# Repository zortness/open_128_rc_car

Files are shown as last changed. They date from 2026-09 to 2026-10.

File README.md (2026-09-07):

# 1:28 Scale 3D Printable RC Car #
This is a collection of 3D files built in [FreeCAD](https://www.freecad.org/). 
It began as a project with a goal of making the least expensive viable RC car that
would still be suitable for competitions for STEM programs in schools. 

See the [History](doc/history.md) page for more info.

## Current State ##
As of Summer 2026, the Mid-Tier cars we've built and assembled are competitive with
box-stock cars of the main manufacturers. 

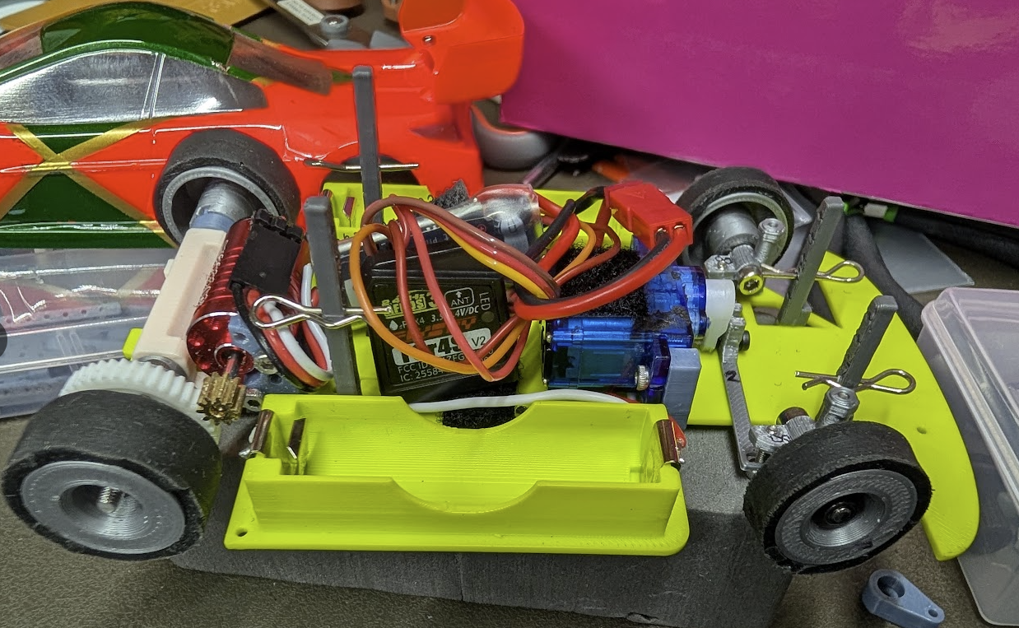
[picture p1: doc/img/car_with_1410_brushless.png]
brushless

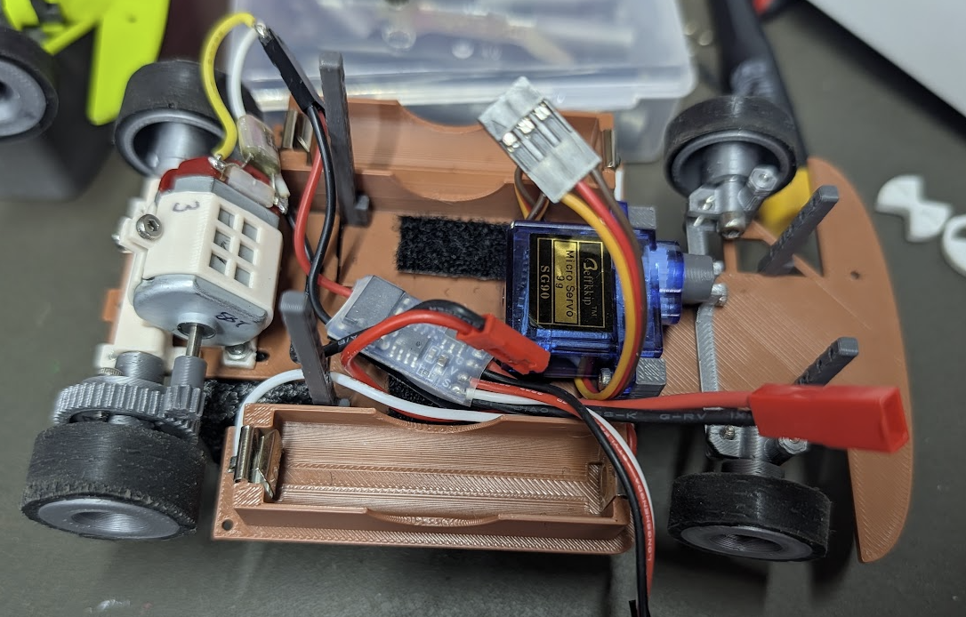
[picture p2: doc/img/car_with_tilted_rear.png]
brushed_tilted

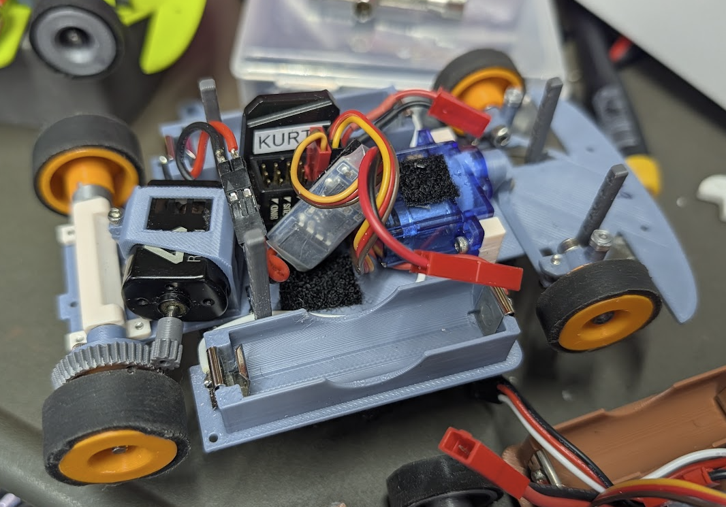
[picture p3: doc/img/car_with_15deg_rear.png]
brushed_15deg

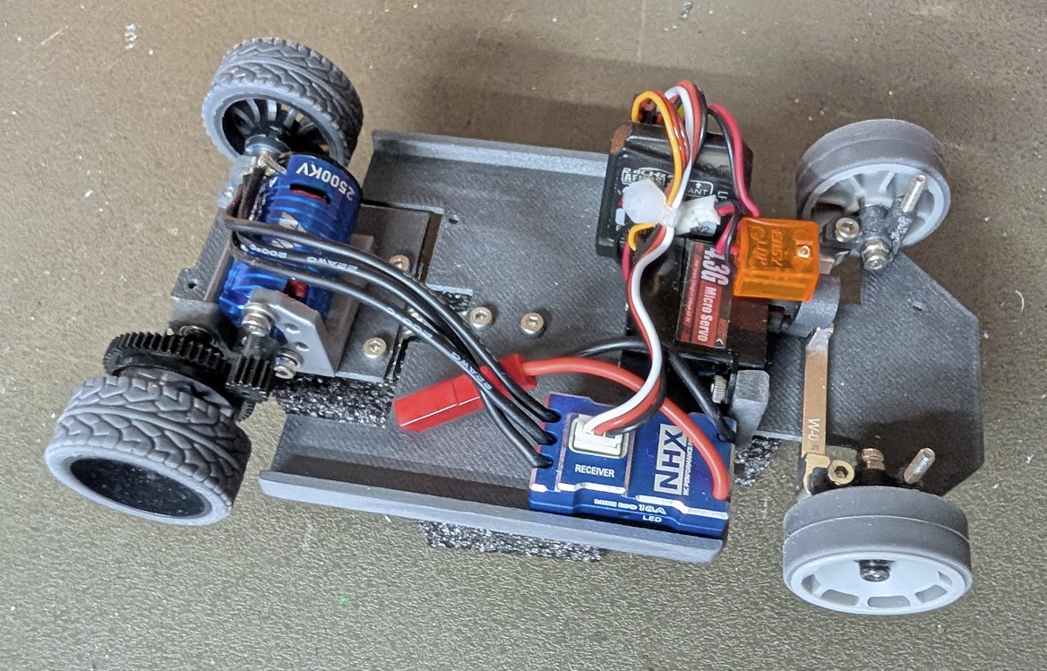
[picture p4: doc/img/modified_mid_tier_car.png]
modified


## Downloading ##
See the releases tab for the latest releases. These packages contain the most common
files and variants that should be more than enough to get you started with a functional
car.

## Materials Needed ##
You will need several [materials](doc/materials.md) and tools. This documentation
will try to walk through the recommended options to get started with the basics.

## Printing and Assembly ##
See [Getting Started](doc/gettingstarted.md).
See [Printing](doc/printing.md) and [Assembly](doc/assembly.md).

## Building from Source ##
You will need [FreeCAD 1.1](https://www.freecad.org/) or higher.
- With Gear Workbench installed (required)
- With Fasteners Workbench installed (required)
- With History Workbench installed (recommended)

You will need [Python 3.14](https://www.python.org/downloads/) or higher to run some of
the tools, like the automated exporter. See [Exporiting](doc/export.md).

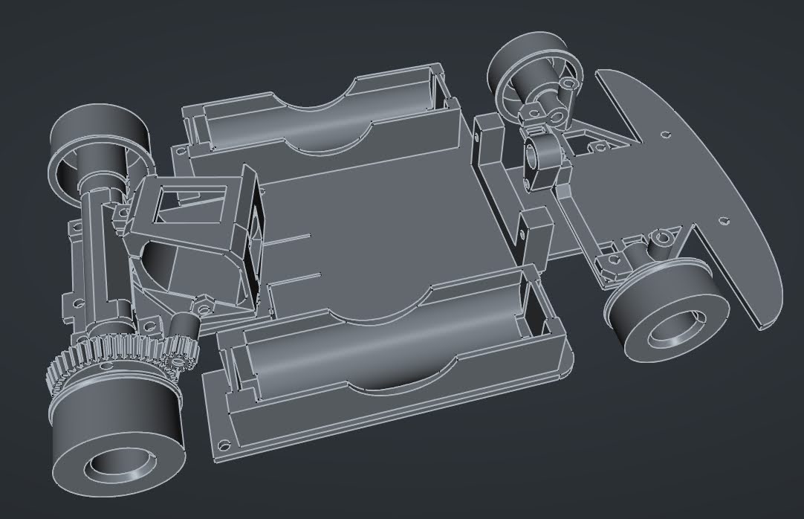
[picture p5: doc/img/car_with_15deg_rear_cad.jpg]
brushed_15deg_cad


## Advanced Topics ##
For the truly adventurous, you can make your own [tires](doc/tires/diytires.md).

## Contributing ##
See [Contributing](doc/contributing.md) for more info.

## Index ##
- [Getting Started](doc/gettingstarted.md)
- [Printing](doc/printing.md)
- [Materials](doc/materials.md)
- [Assembly](doc/assembly.md)
- [Electronics](doc/electronics.md)
- [Batteries](doc/batteries.md)
- [Trasmitters and Receivers](doc/receivers.md)
- [Tires](doc/tires/tires.md)
- [DIY Tires](doc/tires/diytires.md)
- [Exporting](doc/export.md)
- [History](doc/history.md)
- [Contributing](doc/contributing.md)
- [Licenses](LICENSE.md)

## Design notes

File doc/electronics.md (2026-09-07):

# Electronics #
There are an innumerable number of options for electronics for this project.
This section will be presented in tiers depending on budget and goals.

## Prelude ##
We recommend starting with the budget options, unless you have experience
with 1:28 scale cars and understand what the tradeoffs are. But as an example,
once you start upgrading your powertrain, you will start finding the weak points
with each connected piece of the chassis, and will need to start upgrading more
parts to keep the car running. For instance, once you go beyond a budget motor,
you can no longer 3D print your pinion gears and expect to finish a race event,
and will need to buy brass gears and corresponding equipment to manage them. 

An unmodified budget car is typically not fast by 1:28 standards, but is plenty
to get a beginner started on their journey, and plenty of fun in their own right,
especially on small or constrained tracks.

If you want to be competitive with commercially available starter-cars from the main
brands, you will need to aim for a Mid-tier build.

If you want to be competitive with commercially available high-end cars, you will
need to experiment and spend accordingly. Please share your experiments and findings
as this hasn't been achieved by our team yet.

### Transmitter and Receivers ###
See [Transmitter and Recievers](receivers.md).

### Batteries ###
See [Batteries](batteries.md).

### Motor KV ###
The KV gives some indication of the expected RPM at a given input Voltage. 
We typically don't want a high KV if the car is running at 6V or higher. The
range for these cars is typically 2500kV to 4000kV. You can use higher, but 
the car may have trouble driving slowly. If you run the car at 4V, you can use a
higher KV.

Brushed motors typically don't advertise the KV, so you might need to conversion
between Turns (how many windings of copper wire are around the rotors) to KV. 

### Electronic Speed Controller (ESC) ###
You will need to check the input voltage and type of ESC and make sure it's
compatible with your Battery choice and motor choice. Most ESCs will advertise
their upper and lower voltage limits, as well as their Current limits.

For these cars under normal conditions, we are very unlikely to see more than
a few Amps of current. If you are building a very high powered car, most of
the expensive ESCs are capable of 18-20 Amps without issue.

### Tools and Equipment ###
You will likely need a soldering iron, as many of these budget options will have
connectors that are not necessarily compatible with one another. The 
[PINECIL](https://pine64.com/product/pinecil-smart-mini-portable-soldering-iron/)
is a very popular budget soldering iron that works very well if you have a 
good USB-C charger to power it. ($26)

It is often preferrable to solder the motor to the ESC, but you will need to
have a connector setup between the battery(ies) and the ESC.

For the Servo, Receiver, and ESC to connect together, we typically use the
3-pin 0.1" (2.54mm) connectors, somtimes known as JST-XH connectors. 
If you do need to make one of these connectors, they require a crimping tool. 
You can find [these on amazon](https://www.amazon.com/2020-Piece-Connector-Ratcheting-Crimping-Terminals/dp/B0G2L3LGWD/) 
with a crimp tool and a bunch of connectors that you won't need, but it can get
you started. If you want higher quality components, I recommend using parts
from [Hansen Hobbies](https://www.hansenhobbies.com/products/connectors/servoconnectors/).

## Budget Options ##
In the budget range, you are looking for a Brushed 130 size motor. There are
hundreds of these out there to try, and they will run from about $1 to $8 a 
piece for the inexpensive variants. If you get lucky, you might be able to find 
one with carbon brushes instead of copper. Copper also works fine, but carbon 
brushes should last longer.

Copper Brushes:
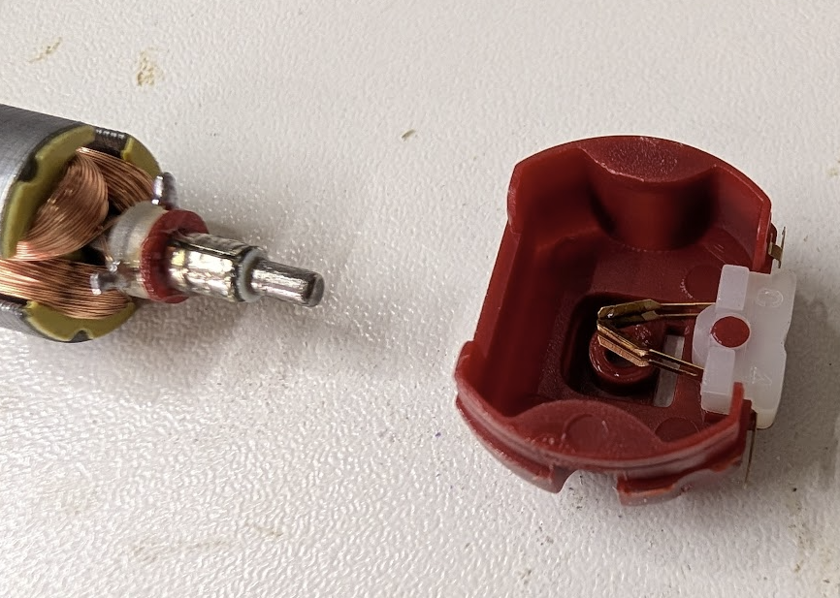
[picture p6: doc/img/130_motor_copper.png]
copper_motor


Carbon / Graphite Brushes:
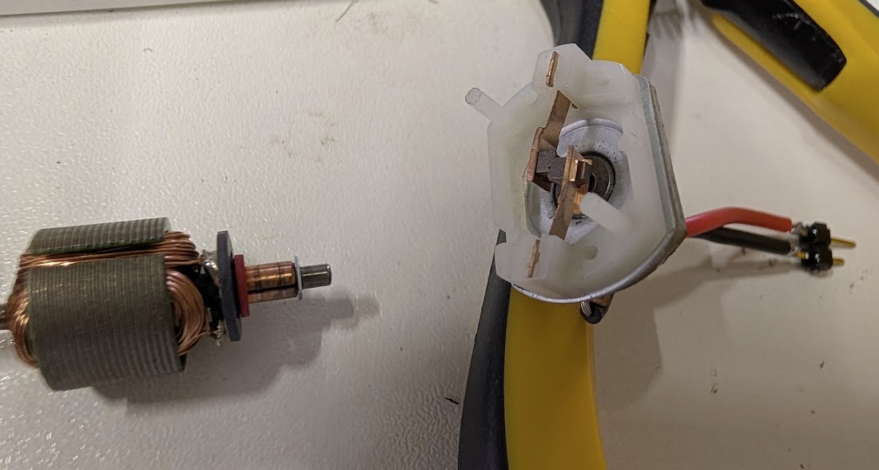
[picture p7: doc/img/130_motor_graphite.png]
carbon_motor


With these budget motors, sometimes it's possible to modify them by taking them
apart and reducing the number of windings to increase the KV. This will speed up
the motor, but likely reduce the lifespan.

budget_car

We have tested these [10-packs of inexpensive 130 motors](https://www.amazon.com/dp/B078MR3H45) 
for many hours and modified several of them. ($14 for 10)

Beware that most of the Tamiya motors are very fast, but also burn through 
brushes very quickly, as they are designed to run around 3V. 

These [6-packs of ESCs](https://www.amazon.com/dp/B0GH65NNN8) are the cheapest budget option
that we have had success with. However, we have certainly burned out a few of these.
The build quality and QA are not great. ($17 for 6)

For the servo, you do not need to spend a lot of money here, especially on a lower
powered car. What you gain in servo upgrades are turning speed and size/weight.
The inexpensive [10-packs of servos](https://www.amazon.com/dp/B08KY49SFX) in the
ubiquitous cheap-servo-blue cases are a great budget option. ($19 for 10)

## Mid-Tier Options ##
There are numerous Brushed Motor and ESC combinations advertised on Ebay and AliExpress.

### Brushed ###
Racing Brushed Motor and ESC.
- [TG Racing 130 Motors on AliExpress](https://www.aliexpress.us/item/3256808970209600.html) ($10 for 1)

tg_motor

### Brushless ###
Budget Brushless Motor and ESC.
- [NHX 2500KV Brushless Motor and ESC Combo on Ebay](https://www.ebay.com/itm/133949755095) ($60)
- [YSIDIO 1410 Brushless Motor and ESC on AliExpress](https://www.aliexpress.us/item/3256805346661858.html) ($37)

ysidio_motor
nhx_motor

### Servos ###
You are looking for inexpensive metal gear servos for speed and durability:
- [MG90s Metal Gear Servo on Amazon](https://www.amazon.com/dp/B0CP98TZJ2) ($14 for 4)
- [TG Digital Servo on AliExpress](https://www.aliexpress.us/item/3256808443190336.html) ($18 for 1)

Or inexpensive sub-micro servos to save space/weight:
- [4.3g Sub-Micro Servo on AliExpress](https://www.aliexpress.us/item/3256808612960463.html) ($5 each)

## High-End Options ##
At the high end, you are looking for a Sensored Brushless Motor and ESC. You can find these from
companies like HobbyWing and PN Racing. These setups will typically run about $150-$200.

You are also looking for a high-torque sub-micro digital servo with metal gears. These are made by
HobbyWing, PN Racing, Torq, and others. These will typically run about $60-$80.

Look for these at established hobby shops, like [A-Main Hobbies](https://www.amainhobbies.com/),
[Kenon Hobby](https://www.kenonhobby.com/), or your local hobby shop.

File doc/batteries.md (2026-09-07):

# Batteries #
There are multiple options for batteries in these cars. This is somewhat dependent 
on which electronics are chosen, but most electronics will be tolerant to a wide
range of voltages.

In general, unless you are using a specific 1S ESC (uncommon), your battery setup
needs to achieve at least 6 Volts, and more typically close to 8 Volts.

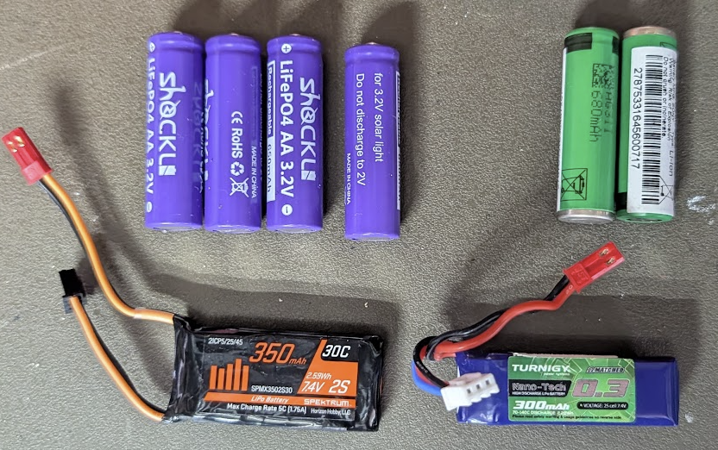
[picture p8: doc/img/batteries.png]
batteries


## Battery Configuration ##
To build a 6V to 8V battery pack voltage range will require at least 
2 cells in series in most cases. Sometimes more.

2-cells in series is referred to or abbreviated as "2S", which doubles the voltage.
If you were to run 4-cells, with 2 parallel groups of 2 in series, this would be
referred to as a "2S2P" configuration, with the same voltage as the 2S configuration.

A single cell by itself would be referred to as a "1S" configuration.

## Basic Chemistry Lesson ##
There are many types of batteries out there in the wild, and we do need to know a
bit about them when making our choices, since the battery performance, charging, 
and safety factors are all considerations.

### Lithium Polymer ###
These are the most common "silver pouch cell" batteries that you find. They are 
typically made of a Lithium-Cadmium mixture and have a very high power density. 
These are the de-facto in the RC hobby. However, they are also the most volatile
and require the most care to avoid dangerous situations. These batteries require
special chargers and can never be overcharged or drop below certain voltages. 
They also degrade a bit with each charge/discharge cycle, leading to eventual 
breakdown and will need to be disposed.

These should be charged in a safe area, even within a fire-proof bag. 
These should be stored at a safe "storage voltage", typically around 50-60% of 
charge capacity, to prevent degredation. Do not store charged or discharged for
long periods (more than 24 hours).

A typical Li-Po cell is advertised as 3.7V, but will charge to 4.2V and discharge
to 3.1V. They need to be stored around 3.6V.

### Lithium Ion ###
These are the most common type of industrial-use Lithium chemistry cells, and will
almost always come in a metal cylindrical format. These are very energy dense, but
you take a penalty in weight for the metal container and protection circuits that
come with the cell. 

These are most commonly found in the 18650 size (18mm x 65.0mm cylinders). You can
also find these in 14500 size, which is mostly compatible with AA carriers.

While these are extremely energy dense, their metal casings and (typically) built-in
protection circuits mean they are quite durable compared to Li-Po pouch cells. You still
have to treat them with respect, but they can take much more of a beating on 
charge, discharge, and general usage.

A typical Li-Ion cell is advertised at 3.7V, will charge to 4.2V, and discharge to
3.0V. They should be stored around 3.6V.

### LiFe PO4 ###
Lithium-Iron-Phosphate is a common type of battery, but typically for lower power
density than its Lithium Cadmium and Lithium Ion bretheren. LiFePO4
has the distinct advantage of being less volatile (less likely to catch fire), and
more resistant to harsh charge and discharge cycles. However, they hold less capacity
per weight than the other Lithium variants.

You can find LiFePO4 cells in both pouch and cylindrical forms.

A typical LiFePO4 cell is advertised as 3.2V, but will charge to 3.6V and discharge to 
2.8V. They should be stored around 3.3V. 

### Sodium Ion ###
These are new (as of 2026) and much less common. They have less power density than
LiFePO4, but have almost zero fire risk. They are mostly used in battery backup 
applications, but you may find them in 18650 sizes.

Na-Ion batteries seem to be advertised as 3.2V, but will charge to about 3.8V
and discharge to about 2.5V. 

### Nickel Metal Hydride ###
NiMH is your run-of-the-mill rechargeable household battery. They are reliable, cheap, 
and safe, but they have the lowest energy density and cell voltage on this list. They
also have the highest variance in cell quality, meaning you can have really good 
or really terrible performance, depending on the battery brandh. 

Instead of being able to run 2S (2 in series) like the lithium batteries, we will 
need to run at least 4S when using NiMH. This is how a stock Kyosho car will come, with
4x AAA-sized NiMH batteries required.

## Specific Recommendations ##

### LiFe PO4 AA-Size ###
This is one of the simplest and cheapest options. 
These used to be found under the Shockli brand on Amazon, but they seem to have 
been discontinued there. You can find similar 600mAh capacities on 
[AliExpress](https://www.aliexpress.us/item/3256812105244901.html)
and other sites. The will be advertised as 3.2V 14500 size LiFePO4 batteries. 
These require a specific type of caddy charger that can be set to the proper voltage.

### Turnigy 2S LiPo ###
HobbyKing, a popular RC retailer, owns the Turnigy brand of batteries. They make
a large number of sizes and configurations for most RC applications. We have found
this [Turnigy 300mAh 2S pack](https://hobbyking.com/en_us/turnigy-nano-tech-300mah-2s-70c-hr-technology.html) 
to be a good choice for these cars, and they are reasonably cheap when they're in stock.

### Chargers ###
Look for a multi-chemistry charger with balancing capability, especially if you are
going to use LiPo or LiIon batteries.

- [Turnigy Accucel C150](https://hobbyking.com/en_us/turnigy-us-plug-accucell-c150-lihv-ac-dc-1-6s-10a-150w-smart-balance-charger.html) ($36)

## Connectors ##
[XT-30](https://www.amazon.com/dp/B0875MBLNH). The XT-30s are overkill for our purposes
but they have the advantage of being a soldered connector, so they can be re-used on
several different projects and easily repaired.

[JST](https://www.hansenhobbies.com/products/connectors/miscconnectors/). These are common
2-pin red connectors. They are nice and small, and plenty durable for our purposes. Their
downside is that they require a small crimping tool to attach the pins to the wire, so 
they are essentially single-project-use if you ever have to cut one away without a lead wire.

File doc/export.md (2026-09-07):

# Exporting Files #

## Requirements ##
You will need FreeCAD 1.1 or higher installed.
You will need Python 3.14 or higher installed.

## Running The Exports ##
To run the default export configuration:

```bash
cd tools
python freecad_exporter.py export
```

This will generate a `dist` folder with all of the default STL files based
on the configuration included. 

To export parametric variants (special cases):

```bash
cd tools
python export_parametric_variants.py 
```

## Possible Issues ##
The python tools were written on a Windows machine with FreeCAD installed in the 
default directory, and will make some assumptions along those lines. If that is not
your situation, you may need to modify the Python files. I will probably eventually
fix these to be more flexible.

## Advanced Configuration ##

### FreeCAD Exporter ###
You can modify which files are exported from the FCStd files and how they are
named by modifying the `export_config.json` file. This file can also be edited
by the `freecad_exporter.py` program in `config` mode. 

```
[Scan] Scanning 23 .FCStd files in '..\modular_car'...

================================================================================================
INTERACTIVE EXPORT CONFIGURATION
================================================================================================
#    Status   Format  File                         Label                      Output File
------------------------------------------------------------------------------------------------
1    [x] ON   STL     01_PanChassisTwoPiece.FCSt   TwoPiecePanMainPlate       PanChassisTwoPieceMain.stl
2    [x] ON   STL     01_PanChassisTwoPiece.FCSt   RightSteeringKnuckle       SteeringKnuckle_Right.stl
3    [x] ON   STL     01_PanChassisTwoPiece.FCSt   SteeringLink               SteeringLink.stl
4    [x] ON   STL     01_PanChassisTwoPiece.FCSt   LeftSteeringKnuckle        SteeringKnuckle_Left.stl
5    [ ] OFF  STL     02_WheelProxies.FCStd        RightRear                  RightRear.stl
6    [ ] OFF  STL     02_WheelProxies.FCStd        RightFront                 RightFront.stl
...
```

Running in config mode will list all possible bodies in the FCStd files of the
repo and give you the option to select which ones should be included in the
export process. 

### Exporting Parametric Parts ###
The `export_parametric_variants.py` program will default to exporting the 
1410 motor mounts with various values. It does have a variety of input options:

```
usage: export_parametric_variants.py [-h] [--file FILE] [--varset VARSET] [--param PARAM] [--increments INCREMENTS] [--body BODY]
                                     [--format {stl,step,3mf,obj}] [--outdir OUTDIR] [--suffix-template SUFFIX_TEMPLATE]
                                     [--linear-deflection LINEAR_DEFLECTION] [--angular-deflection ANGULAR_DEFLECTION]

FreeCAD Parametric Variant Exporter

options:
  -h, --help            show this help message and exit
  --file FILE           Path to .FCStd file (default: modular_car/15_1410MotorFlatRear.FCStd)
  --varset VARSET       Name of VarSet object (default: auto-detect '1410MotorMountVars')
  --param PARAM         Target parameter name (default: MountOffset)
  --increments INCREMENTS
                        Comma-separated list of increment values (overrides VarSet array)
  --body BODY           Name/Label of PartDesign::Body to export (default: auto-detect)
  --format {stl,step,3mf,obj}
                        Export format (default: stl)
  --outdir OUTDIR       Output directory (default: dist)
  --suffix-template SUFFIX_TEMPLATE
                        Suffix template (default: '_offset_{val}mm')
  --linear-deflection LINEAR_DEFLECTION
                        Linear deflection for mesh export (default: 0.01)
  --angular-deflection ANGULAR_DEFLECTION
                        Angular deflection for mesh export (default: ~10 deg)
```

The parametric export is useful for parts that may need several different sizes based on
an input variable.

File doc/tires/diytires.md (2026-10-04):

# DIY Tires #
Why would you want to make your own tires? Tires ended up being one of the most
expensive parts on the original Bill of Materials for this projects. This fed 
the desire to explore possible methods for creating our own tires at a lower
cost.

While searching the internet, we came across videos from [@nick_cnc](https://www.youtube.com/@nick_cnc/videos)
that demonstrated a method for creating tires using a urethane casting resin. Nick's
videos were extremely helpful in allowing us to come up with a general recipe that
worked for our cars, but there is a lot of room left to experiment.

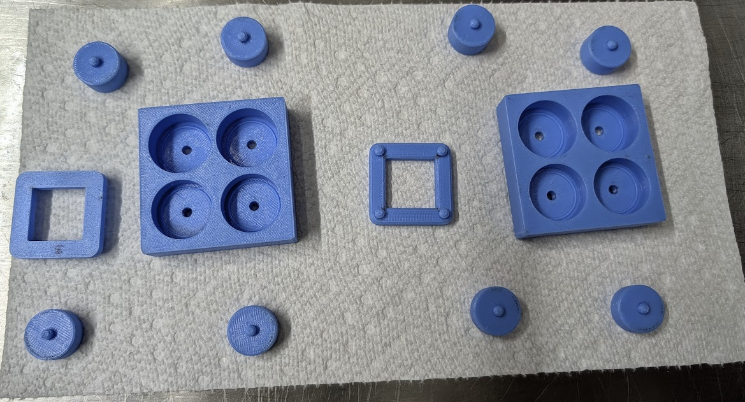
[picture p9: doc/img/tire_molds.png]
tire_molds

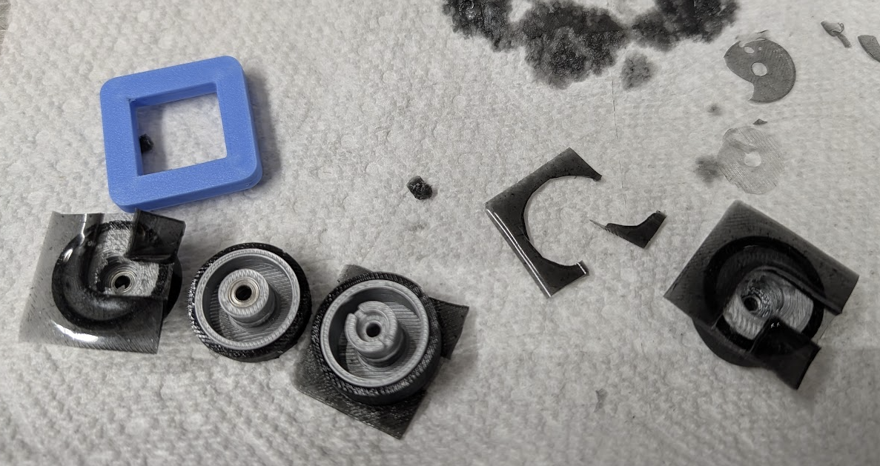
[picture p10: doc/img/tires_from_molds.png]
tires


- [Video 1 - Results](https://www.youtube.com/shorts/KFW3lIj04KQ)
- [Video 2 - Mold Prep](https://www.youtube.com/watch?v=bqIWgSsQQlw)
- [Video 3 - Heating](https://www.youtube.com/watch?v=EFLkVkMNqh4)
- [Video 4 - Mixing Prep](https://www.youtube.com/watch?v=rZVht2L4nNo)
- [Video 5 - Pour Prep](https://www.youtube.com/watch?v=ZeqlwVe74fA)
- [Video 6 - Mixing](https://www.youtube.com/watch?v=JHCaA9XlHv4)
- [Video 7 - Pouring](https://www.youtube.com/watch?v=PlN8m7KV1bo)
- [Video 8 - Curing](https://www.youtube.com/watch?v=UfTrvAAhHPg)

## Materials ##
Assuming you already have a 3D printer, you are looking at about $100 in materials to get started. 
At about $7 for a set of front tires, and $8 for a set of rears, you will need to
make more than 7 sets of tires to recoup your costs. 

We have not exhausted our first purchase along these lines, but I expect 50+ sets of
tires can be made from the materials below, which would bring the cost down to about $2
per set.

### Urethane Mix ###
Similar to @nick_cnc's videos, we started with the VytaFlex brand of urethane mixes,
although, so far, we've only used Shore 20 hardness, which is the softest available.
With a [pint unit](https://www.amazon.com/dp/B00IRC0MJW), we have made over 20 sets of
tires, and still have probably 2/3rds of the batch remaining. It's more likely that
the mix goes bad than run out of material in any normal timeframe. ($30)

### Mold Release ###
The [Smooth-On Universal Mold Release](https://www.amazon.com/dp/B004BNHLOK) has worked
well in our testing so far, and there hasn't been any reason to change. ($22) 

### Carbon Black / Lamp Black ###
This is essentially very pure carbon powder. It can be found on the internet in various places
but you need to look for a reliable source that will provide high quality powder. The Inoxia
brand on Amazon seemed to work well, [example item](https://www.amazon.com/dp/B00B0CJDBE). 
100 grams will last a very long time, as you need less than a gram per batch. ($16)

### Printed Tire Molds ###
We printed the tire molds in a harder TPU (Bambu's [TPU For AMS](https://us.store.bambulab.com/products/tpu-for-ams)). 
It has a bit of flex but the real property we're after is the smoothness and layer adhesion for this process.
Other printing materials may work as well, but TPU is the only thing that's been tested so far. ($35)

### Additional Considerations ###
- You will need a scale with .1g resolution. These are readily available on Amazon and other retailers.
- You will need disposable cups (plastic) to pour the urethane. Glass can also work, but they are a lot of work to clean after.
- You will want a tray or pan to use when applying the mold release.
- A heat gun is very useful; a hair dryer may also work.
- A floor heater is useful for pre-warming the urethane mix.
- A heated chamber would probably be ideal, but we haven't used this method.
- A vacuum pump and small chamber is likely ideal, although we haven't used this method.
- A tiny measuring spoon is helpful with the carbon black; the sizes are non-standard, but you want about 2mm x 3mm x 1mm deep, which should be about a quarter of a gram
- You will need mixing sticks, such as food grade popsicle sticks, which should be readily avialable

## Recipe ##
For Two Sets of Tires. Requires two sets of molds.

The amount of carbon black will determine the hardness, but it is a tiny amount. No carbon black, and you
will get tires that are too soft to use. Too much and you will get dry spots in the tires and they will
tear during use.

Heat is helpful to reduce the amount of bubbles that survive the molding process.

Read through all directions here before attempting.

### [Optional] Pre-Warm the Urethane ###
- Set a space heater on Low
- Place both Urethane canisters 1-2ft away from heater
- Let warm for 10 minutes\
OR
- Place both urethane canisters in heating chamber at 90-100F for 10 minutes

### Prepare The Molds ###
- Apply mold release to main face of both molds and upper braces.
  - A light coating, you don't need to overdo it.
- Let stand for 5 minutes. 
- Flip and apply another coat to the back side of molds.
- Let stand for 5 minutes.
- Apply masking tape to the back side of the molds to plug the release holes.

### Timing Note ###
Everything below this point happens rather quickly. You will need to finish this process in
about 10 minutes. Read through this section before starting.

### Mix Urethane ###
- Part A
  - Turn on scale
  - Set empty cup on scale
  - Tare scale
  - Pour 15g of part A into cup while on scale
  - Set Part A to side
- Part B
  - Set second empty cup on scale
  - Tare scale
  - Pour 15g of part B into cup while on scale 
- Carbon Black / Lamp Black
  - Use tiny measuring spoon to extract about 0.25g of carbon black and tap it into one of the mixes
  - Do not touch your measuring spoon to the mix
- Pour Part A (thinner) into Part B (thicker)
  - mix thoroughly for about 3 minutes with a mixing stick

### Mold Pouring ###
Molds should be within a splash safe area, as urethane will stick to almost anything.
Paper towels can be used under the molds.
Caution, molds are very slick to the touch once the mold release is applied, and can be difficult to handle.

- Use heat gun to warm mixture for 1-2 minutes
- With main mold base empty (no plugs, no upper brace), gently pour in each tire location until the holes are about 3/4 full
- Insert center plugs in the appropriate holes, tilt at about 5-10 degrees during initial contact with the 
    urethane to avoid capturing more air
- Overflow of urethane is expected and should occur at this point. If there's not enough overflowing, use some 
    excess from the batch or another location to fill up and over the edge of the tire area
- With plugs insert, but no upper braces, use the heat gun to go around the molds for 1-2 minutes and apply heat
    as directly to urethane area as possible
- Insert upper braces into plugs
- Use the heat gun across the molds for an additional 1-2 minutes to try and remove as much as as possible

At this point, the urethane is probably starting to get noticeably thicker and the heat gun will have less
and less effect.

If you were going to use a vacuum chamber, probably do it after inserting the upper braces and avoid the last direct
heating step. Timing of vacuum application is uncertain.

You can use something heavy and square to set on top of the mold braces to apply pressure (ex: a box of bolts).

### De-Molding ###
Let the urethane cure for 24 hours before de-molding. 

Use a small screwdriver or similar tool to press up from the release holes on the bottom of the molds. Be cautious
not to stab your own hand, as the the molds will sometimes release suddenly. Take your time.

The 4 tires will probably be attached to a square of urethane that had covered the top side of the mold. 

Wash the urethane tire batches in soapy water to remove mold-release from the tires. 

We tend to leave the tires as a set, attached to the molded square piece, until final installation.

### Installation ###
You can attempt to cut the tires away from the molded square ahead of installation, but this has had mixed
results for us.

The easiest way to install the tires is in a permanent fashion. One at a time, set a wheel 1/3 of the way into a tire, 
and then run a tiny bead of super glue around the protruding rim of the wheel. Use caution as to not get any super
glue onto the urethane ahead of time. In a fast motion, press the wheel quickly all the way into the tire and hold
it for a few seconds. The super glue should cure within a few seconds and the tire is permanently attached to the wheel.

After all 4 wheels are installed, use a sharp small pair of scissors to slowly cut away the excess urethane up to the
face of the wheels.

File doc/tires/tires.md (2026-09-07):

# Tire Options #
Tires are relatively expensive compared to the cost of a basic car
setup. If you are planning on making several cars for a class or 
program, you may want to consider [making your own tires](diytires.md).

If you are only making a small number of cars, it is likely more time
and cost effective to buy a set of tires.

## Tire Sizes ##
The default files in this project have a 20mm diamter. The front wheels
are narrow, at 8.5mm. The rear wheels are wider, at 11mm.

There are several different sizes of tires available, and you can modify
the `08_Wheels.FCStd` file to fit your needs.

## Tire Hardness ##
Hardness is measured on the [Shore scale](https://en.wikipedia.org/wiki/Shore_durometer).
A very soft tire is around 10-Shore, and a very hard tire is around 50-Shore,
in typical RC usage. Because these printed 1:28 are small and light, we will
need to stay toward the lower end of that range to end up with a performant 
car setup. 

## Traction Disks ##
On very fast cars, you will often see disks attached to the outside of the 
front wheels. These disks are usually just slightly less in diameter than the
actual tire (maybe 21mm) and actually reduce front wheel traction in hard corners
to allow the car to understeer (go more straight) in a corner, rather than 
flipping over (a traction roll), or spinning the rear of the car around (oversteer).

The basic wheel files in this project don't account for traction disks, but
you can easily add them to the model files once you start to hone in a desired
car and tire setup.

## Simple Tire Options ##
### Kyosho Mini-Z Tires ###
The "stock" rubber slick tires that come with most Kyosho Mini-Z's are stiff
and slippery, but durable. These are not a great choice unless durability is
your desired factor.

Look for the "Racing Radial" tires from Kyosho for a higher performance tire,
in 20 or 30 Shore (hardness).
- [8.5mm Radial Racing Tire](https://www.amainhobbies.com/kyosho-miniz-8.5mm-racing-radial-tire-4-30-shore-kyomzw37-30/p385402?v=212141)
- [11mm Radial Racing Tire](https://www.amainhobbies.com/kyosho-miniz-11mm-wide-racing-radial-tire-4-20-shore-kyomzw38-20b/p385403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)

### PN Racing Tires ###
These are considered "high end" tires, made of silicone and urethane. They
usually run about twice as much per tire as the Kyosho or other budget options
- [11mm KS-M Low Profile Super Soft](https://www.kenonhobby.com/PN-Racing-Mini-Z-KS-M-Compound-RCP-Low-Profile-Slick-11mm-Tire-Super-Soft-30-Shore-2pc_p_49472.html)
- [8.5mm KS Low Profile Super Soft](https://www.kenonhobby.com/PN-Racing-Mini-Z-KS-Compound-RCP-Low-Profile-Slick-85mm-Tire-SUPER-SOFT-30-Shore-2pc_p_49466.html)

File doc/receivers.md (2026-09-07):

# Transmitters and Receivers #
This is by far the most expensive part of a build. 

## Budget Options ##
Hands down, the [Flysky FS-GT2](https://www.amainhobbies.com/flysky-fsgt2-2channel-transmitter-w-fsgr3e-receiver-fsy-fs-gt2gr3e/p1592821) 
with receiver  is the most durable and recommended transmitter to get started. 
It is not a high precision tool,
but these are incredibly durable and we have some of these that have been abused
by school age children for over a decade and still function. ($30)
The receivers are large, but you can wrap the antennas and stuff them into the car.

These are sometimes sold under different brand names, such as HobbyKing. 

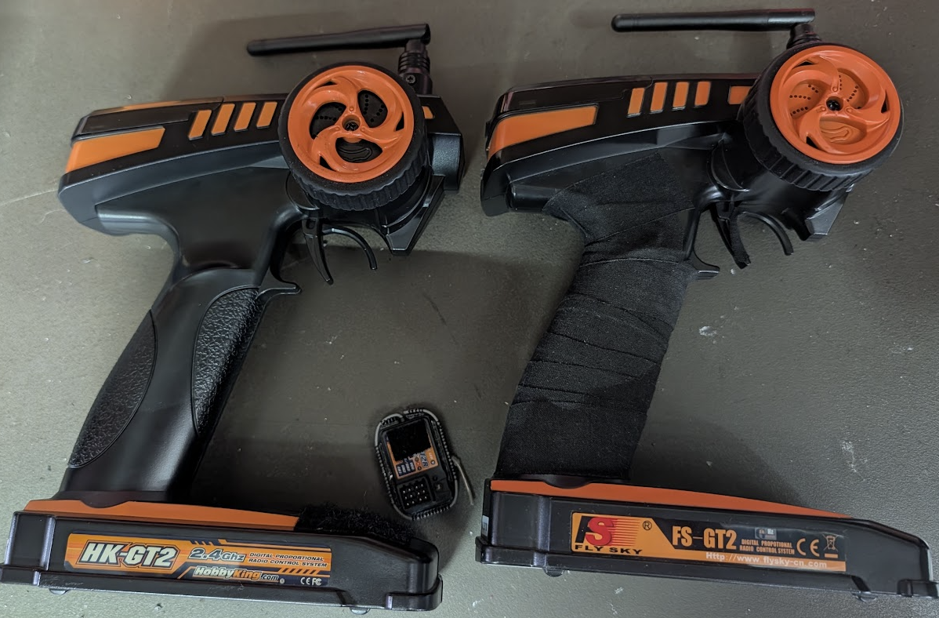
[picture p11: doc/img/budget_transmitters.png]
flysky_trans


## High End Options ##
The most common controllers you will see at a track are the 
[FlySky Noble NB4+](https://www.amainhobbies.com/flysky-noble-nb4-afhds3-8channel-2.4ghz-radio-system-fsy-noble/p1556281)
and the
[Futaba T4PM+](https://www.amainhobbies.com/futaba-t4pm-4channel-2.4ghz-tfhss-sr-radio-system-w-r304sbe-receiver-fut01004415-1/p1656189).

Both of these transmitters are great. Both offer micro receivers that you can use for smaller cars,
but you can also start with the larger receivers and potentially de-body them (remove the plastic) to make space.

## Rececivers ##
Note that manufacturers are constantly changing the protcols for their transmitters
and receivers. You have to check that the specific transmitter and specific receivers
are compatible protocols, and even protocol versions. AFHDS2 is not compatible with AFHDS3
for instance.

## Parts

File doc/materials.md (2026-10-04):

# Materials #
## Prerequisite Tools ##
- 3D Printer
- Small Metric allen wrenches
- Pliers with cutters, or heavy duty cutters, or rotary tool with cut-off wheel (for cutting axles)
- Metal file (for filing axle ends)
- Hobby Knife
- Soldering Iron and related materials
- Super Glue
- Side Cutters (recommended)
- Wire Stripper Pliers (recommended)
- Small Metric Drill bits (recommended)
- Hook and Loop tap (recommended)

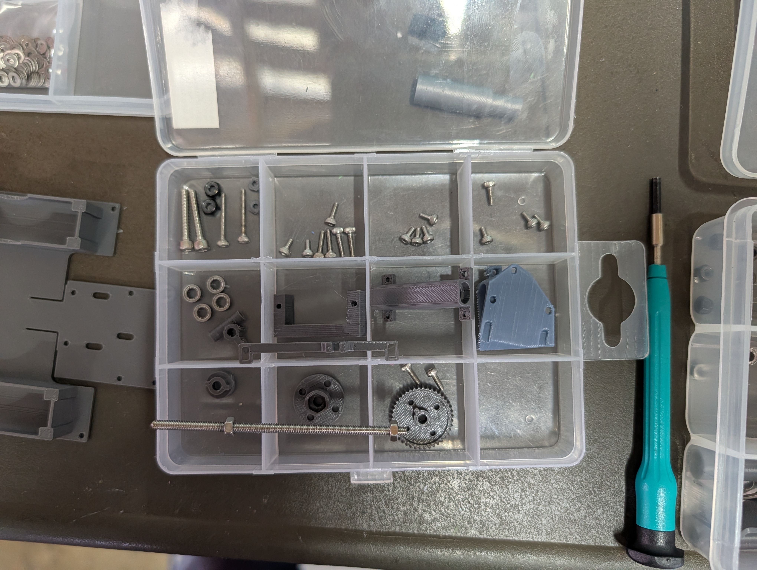
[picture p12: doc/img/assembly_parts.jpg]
assembly_parts


## Basic BoM ##
For the printed parts see [Getting Started](gettingstarted.md) and [Printing](printing.md).

### Screws & Nuts ###
- 1x M3x75mm Threaded Rod (rear axle)
  - 2x M3 steel nuts
  - 2x M3 locknuts (printed or metal + nylon)
- 2x M3x16mm (front axles)
  - 2x M3 locknuts (printed or metal + nylon)
- 2x M2x12mm (front steering uprights)
  - 2x M2 locknuts (printed or metal + nylon)
- 2x M2x8mm (front steering links)
- 2x M2x6mm (servo mounting)
- 2x M2x4mm (servo mount to floor pan)
- 1x M2x6mm (motor mount pinch for brushed motors)
  - 1x M2 nut for motor pinch
- 3x M2x4mm (motor mount to floor pan)
  - 3x M2 Nut for motor mount
- 4x M2x4mm (rear axle mount)
- 2x M2x6mm (main gear mount)

Note: There are several car variations, so the actual number of screws used may differ.

Optional Bundles
- [M3 Threaded Rod](https://www.amazon.com/dp/B0CNLN777Z), needs to be at least 70mm ($6 for 10, makes 20 axles)
- [M3 Screw Bundle](https://www.amazon.com/dp/B0BMQFHDBH) (only for front axles, really only need M3x12mm) ($19)
- [M2 Screw Assortment](https://www.amazon.com/dp/B0D3X33XGB) (makes about 5 cars) ($9)
- [M2 Locknuts](https://www.amazon.com/dp/B0DL5S4F9X) (optional) ($8)
- [M3 Locknuts](https://www.amazon.com/dp/B0DFY8Y1TK) (optional) ($6 for 120)

### Bearings ###
The cars are designed to be built with only one type of bearing, the commonly available MR63ZZ, 
at the tradeoff of needing a couple M3 screws per car. However, you can follow what Kyosho does
and use an M2 front axle, if you can find some MR62ZZ bearings.

- 6x [MR63ZZ Bearings](https://www.amazon.com/dp/B0DY11G865) ($9 for 20)
- (Optional) 4x [MR62ZZ Bearings](https://www.amazon.com/dp/B0DBQV76LD)

6x MR63ZZ per car.

### Battery Contacts ###
If you are starting with the recommended AA-sized batteries, you will need 
contactors to install and solder into the car.

- 2x Positive Contactor - [Keystone 228](https://www.digikey.com/en/products/detail/keystone-electronics/228/528660) ($0.25)
- 2x Negative Contactor - [Keystone 209](https://www.digikey.com/en/products/detail/keystone-electronics/209/151583) ($0.30)

You will need two positives and two negatives per car.

### Wire ###
You will want to have some small gauge wire on-hand. [26AWG](https://www.amazon.com/dp/B089D3T1JD) 
is plenty for these small cars. ($17)

### Brass Gears (optional) ###
The gears included in these prints use the gear measurement of 0.5 Modulus (0.5M). 

Many upgrade gears for 1:28 scale cars use 64-Pitch (64p, or 64 teeth per inch) gears,
which are close to 0.5M but distinctly different, and will not work. The stronger gear 
will destroy the weaker if these two are combined.

Most of the motors you will encounter require a 2mm tight fit gear, which will 
require a gear pulling/installing tool (Pinion Puller) if you decide to use brass gears.

- [Example Pinion Tool](https://www.amazon.com/dp/B0CQ23ZW3G) ($20)
- [Example Gears](https://www.aliexpress.us/item/3256808560628405.html) ($5)

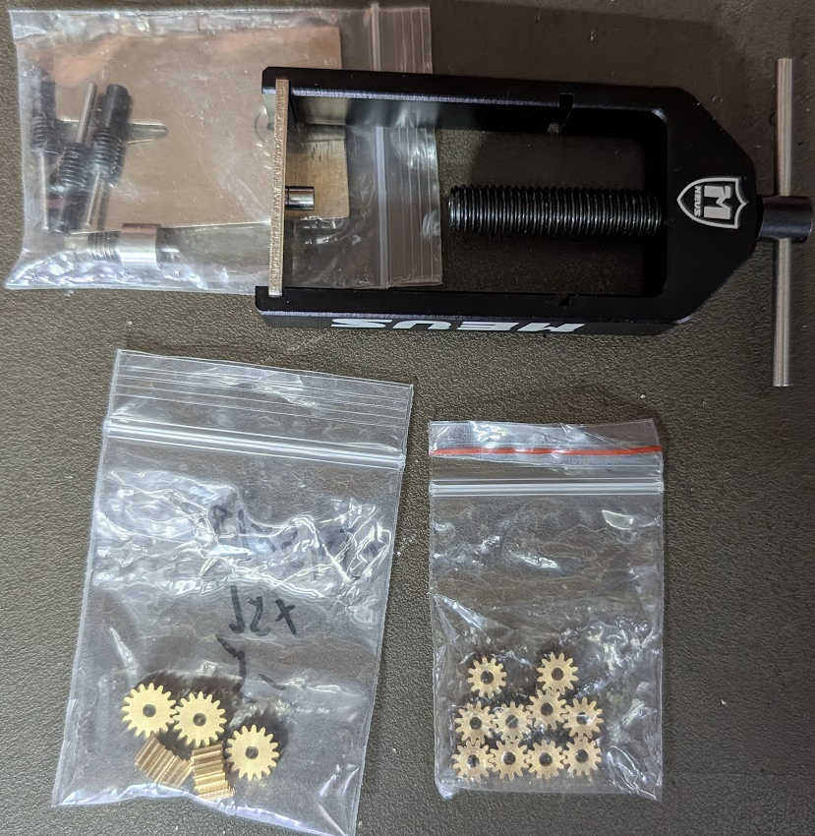
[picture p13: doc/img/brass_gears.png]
brass_gears


## Electronics ##
You will need:
- Motor
- ESC

See [Electronics](electronics.md) for more information.

## Batteries ##
You will need a battery setup with 6-8V range. 
You will also need the appropriate charging capabilities. 

See [Batteries](batteries.md) for more information.

## Transmitter and Receiver ##
You will need a 2-channel transmitter and compatible receiver.

See [Transmitters and Receivers](receivers.md) for more information.

## Operation Surfaces ##
These cars will not work well on rough surfaces like concrete and asphalt.
We recommend smooth surfaces, like wooden or linoleum flooring to start.
If you want to build a track, we recommend buying inexpensive foam flooring tiles
from your local home improvement store and arranging them into a track. This is 
essentially what the official 1:28 tracks are made out of, with nicer barriers
and smoother surfaces.

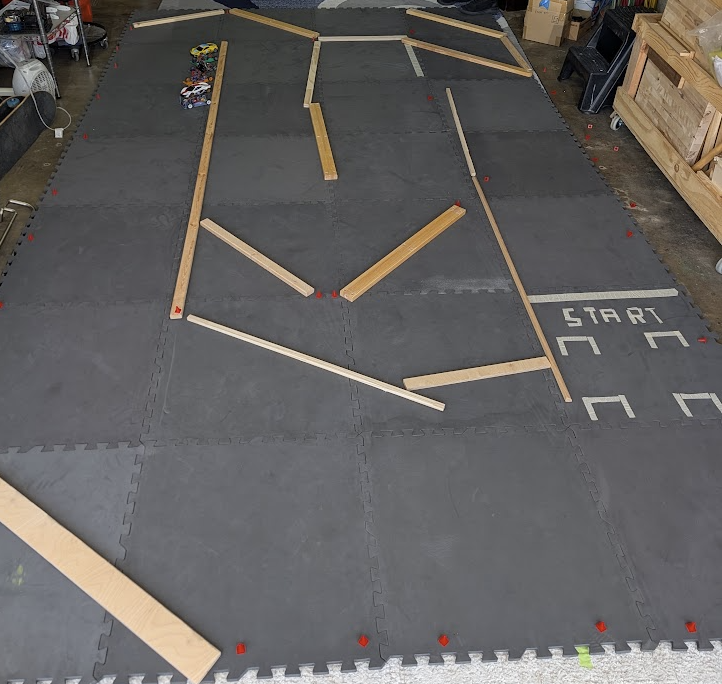
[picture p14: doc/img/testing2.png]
test_track


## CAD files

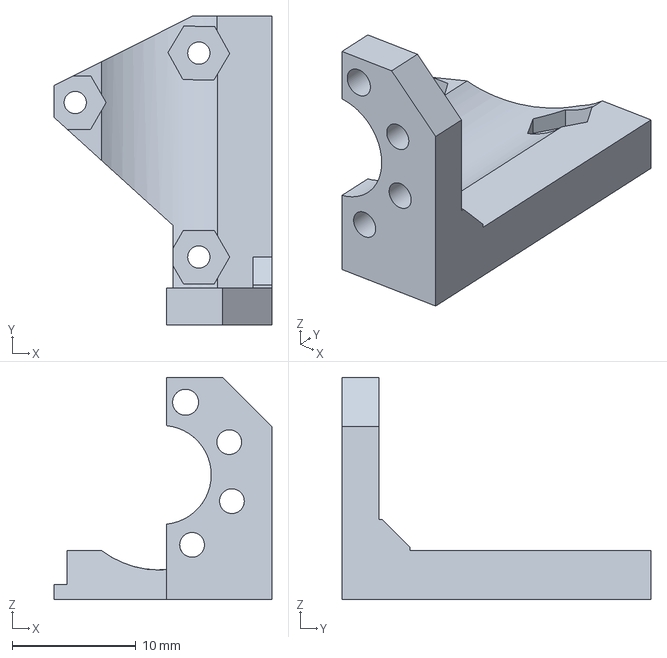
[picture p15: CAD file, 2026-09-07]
modular_car/15_1410MotorFlatRear.FCStd
17.6 x 25.0 x 18.0 mm

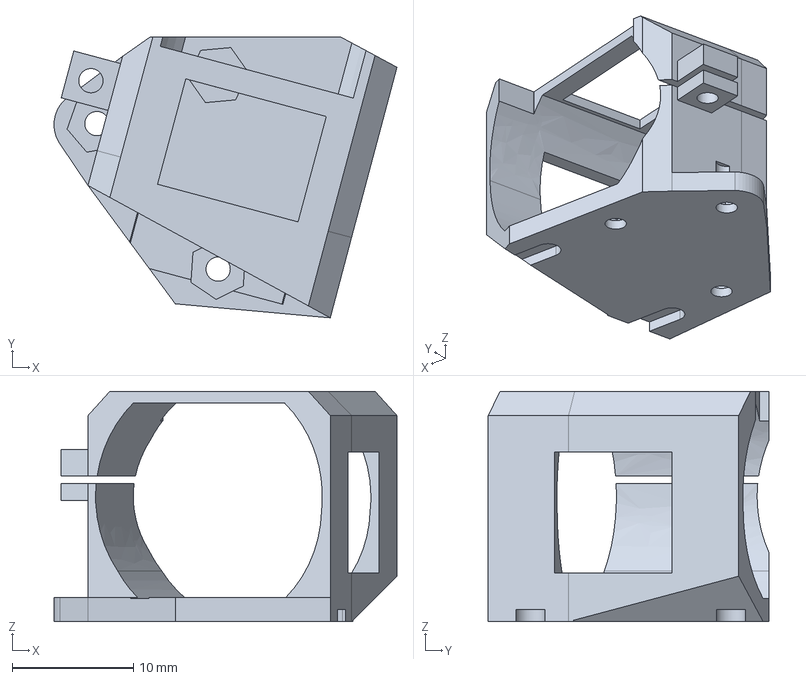
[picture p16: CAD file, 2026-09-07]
modular_car/14_130MotorFlatRear.FCStd
28.3 x 23.2 x 19.0 mm

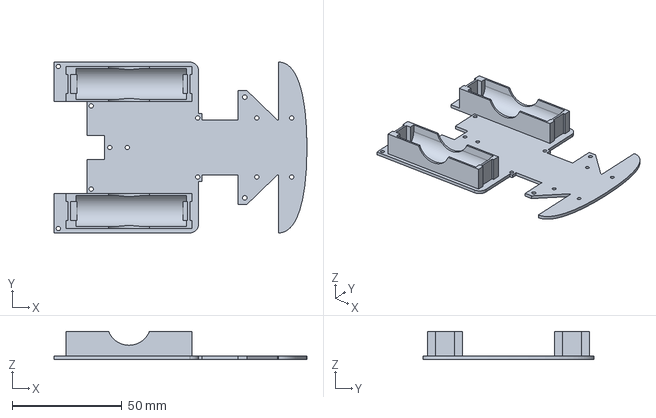
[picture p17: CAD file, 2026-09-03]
modular_car/21_PanChassisThreePiece.FCStd
115.5 x 78.0 x 13.0 mm

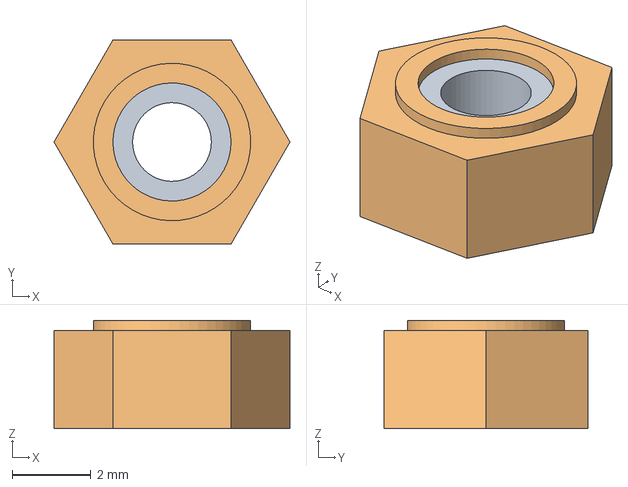
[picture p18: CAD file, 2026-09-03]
modular_car/06_Fasteners.FCStd
6.00 x 5.20 x 2.75 mm
M2PlasticWheelNut4.5mm
M3PlasticWheelNut5.5mm

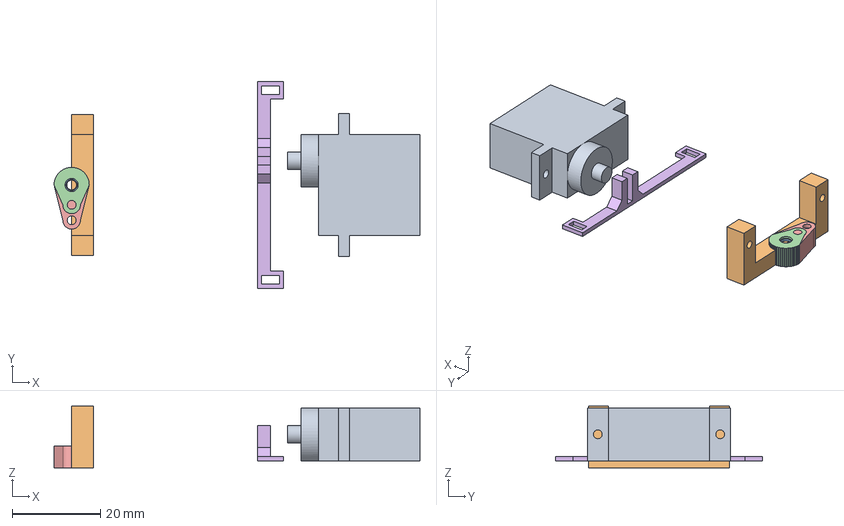
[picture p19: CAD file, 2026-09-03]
modular_car/03_Servo.FCStd
83.0 x 47.0 x 14.0 mm
MicroServo
MicroServoMountLongThrow
MicroServoHorn4.5mmX5mm
SubMicroServoHorn3.8mmX5mm
MicroServoHorn5mmX9mm
SteeringLink

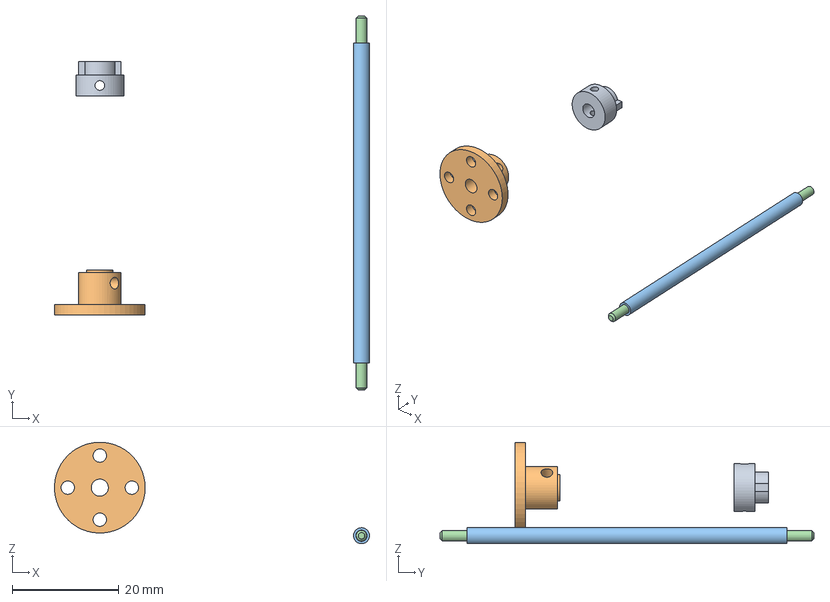
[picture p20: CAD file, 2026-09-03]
modular_car/12_SmoothRearAxle.FCStd
59.0 x 70.0 x 19.0 mm
SmoothRearAxleSpacer
SmoothSolidAxleGearMount
SmoothRearAxleTube
M2x70-ThreadedRod

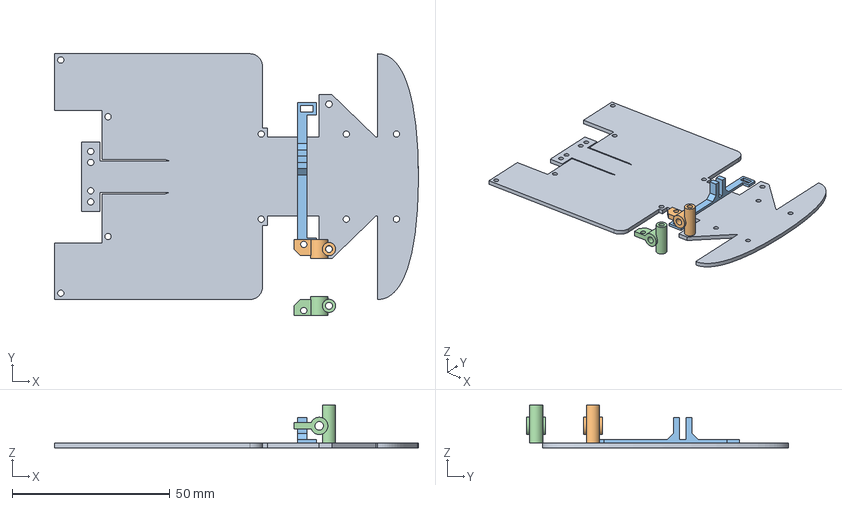
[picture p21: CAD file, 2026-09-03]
modular_car/01_PanChassisTwoPiece.FCStd
115.5 x 83.0 x 13.6 mm
TwoPiecePanMainPlate
RightSteeringKnuckle
SteeringLink
LeftSteeringKnuckle

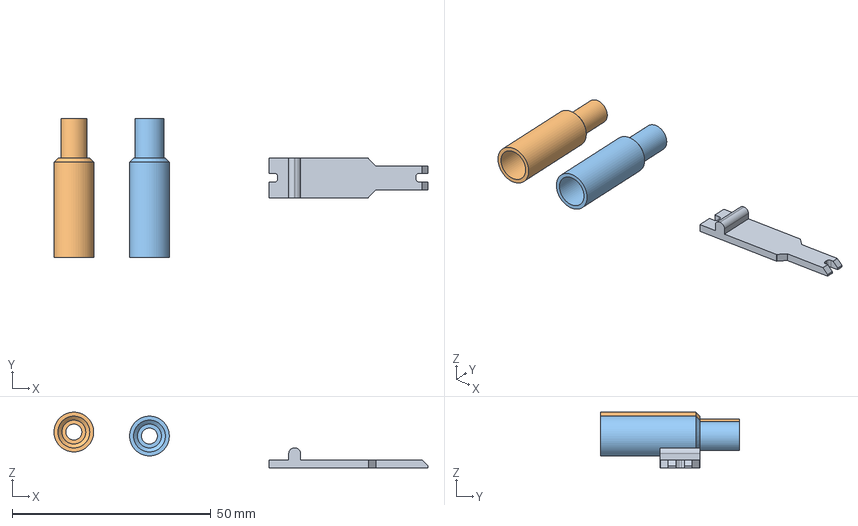
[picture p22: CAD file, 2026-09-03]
modular_car/07_Tools.FCStd
94.0 x 35.0 x 14.0 mm
PinionPuller
WheelNutDriver4.5mm
WheelNutDriver5.5mm

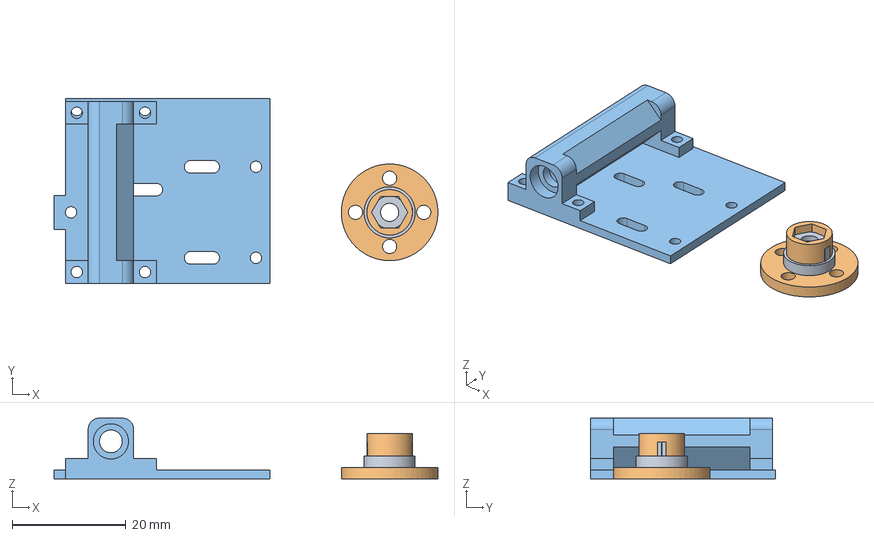
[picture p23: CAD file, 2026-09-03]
modular_car/13_ThreadedRearAxle.FCStd
67.5 x 32.5 x 10.7 mm
ThreadedRearAxleSpacer
ThreadedSolidAxleGearMount
RearPanPlateWithTreadedAxleMount

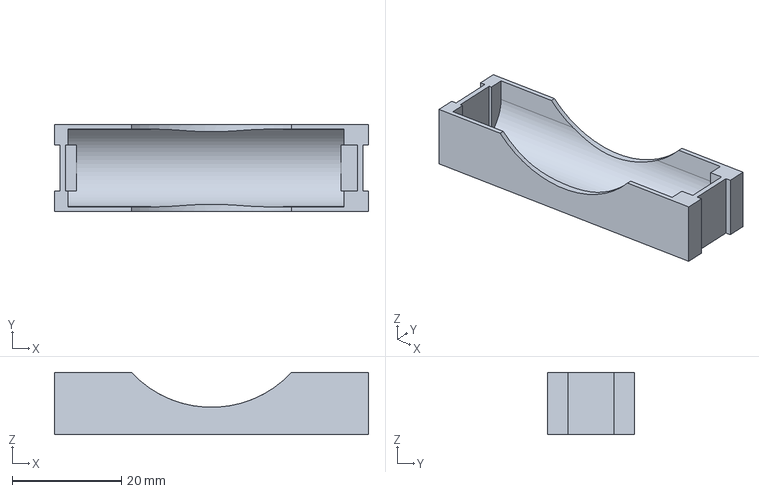
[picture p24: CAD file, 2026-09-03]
modular_car/10_Batteries.FCStd
57.5 x 16.0 x 11.4 mm

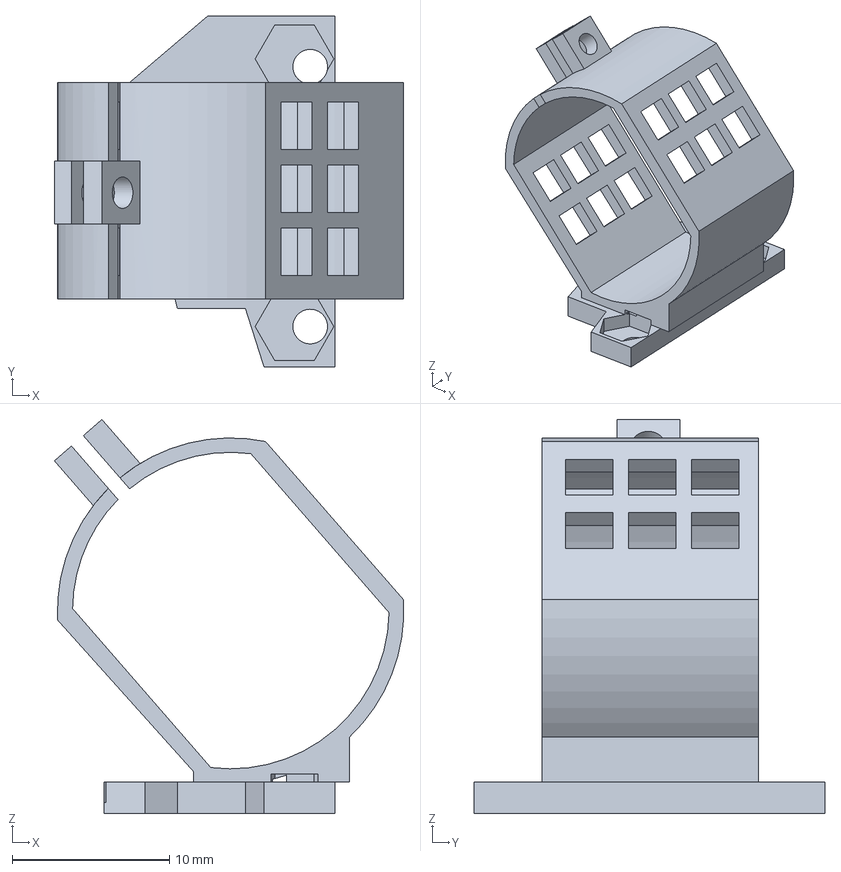
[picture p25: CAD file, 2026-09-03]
modular_car/11_130MotorTiltedRearEnd.FCStd
22.2 x 22.3 x 25.0 mm

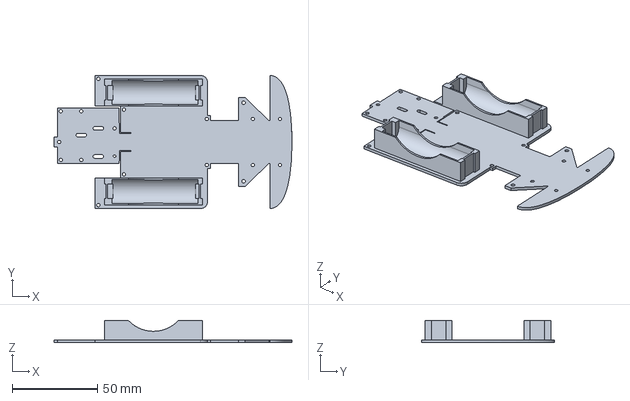
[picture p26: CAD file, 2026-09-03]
modular_car/19_PanChassisSinglePiece.FCStd
139.5 x 78.0 x 13.0 mm

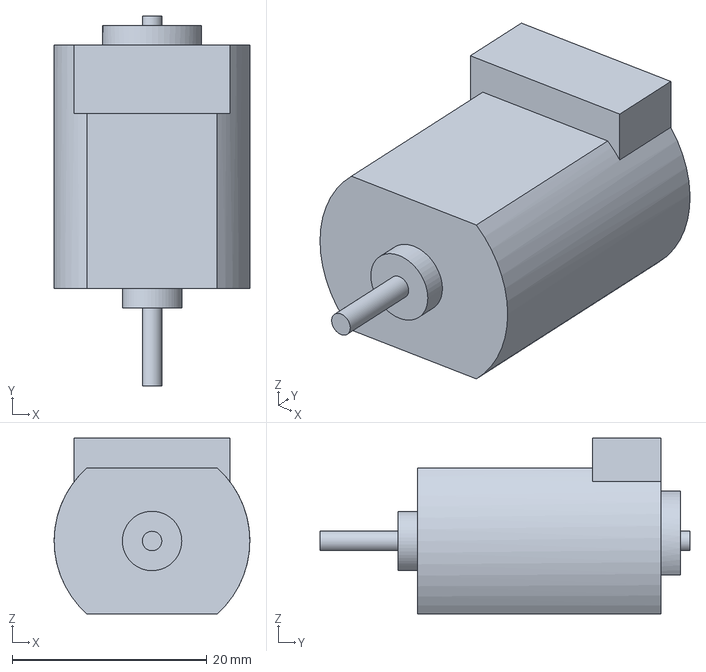
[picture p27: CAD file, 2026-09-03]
modular_car/09_Motors.FCStd
20.1 x 38.0 x 18.1 mm

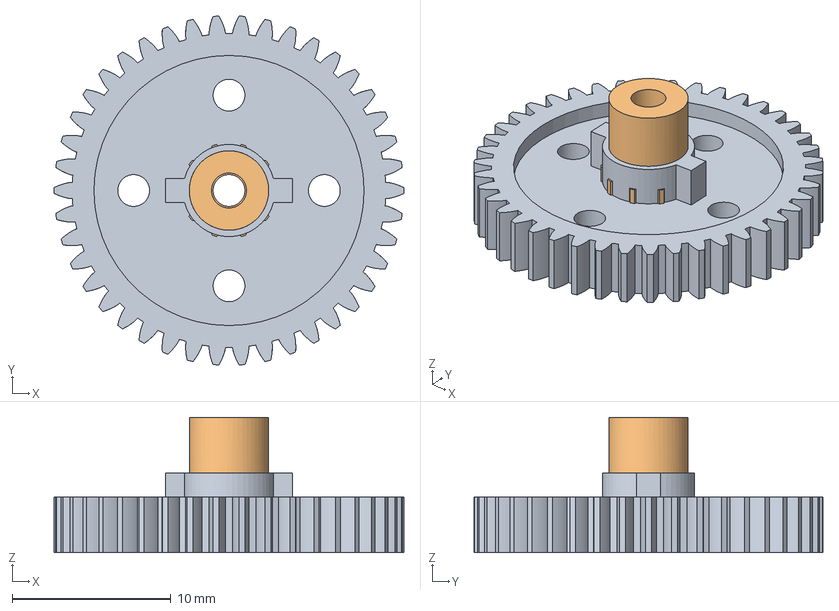
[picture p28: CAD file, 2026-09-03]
modular_car/04_Gears.FCStd
22.0 x 22.0 x 8.50 mm
MainGear42T_M05
Pinion_10T_M05

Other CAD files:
modular_car/00_CarAssembly.FCStd
modular_car/00_RearPanPlateFlatMount.FCStd
modular_car/00_GeometryReference.FCStd
modular_car/16_TireMold.FCStd
modular_car/02_WheelProxies.FCStd
modular_car/05_Bearings.FCStd
modular_car/08_Wheels.FCStd
modular_car/17_TPlate.FCStd
modular_car/18_BodyPosts.FCStd

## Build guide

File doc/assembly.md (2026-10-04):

# Assembly #
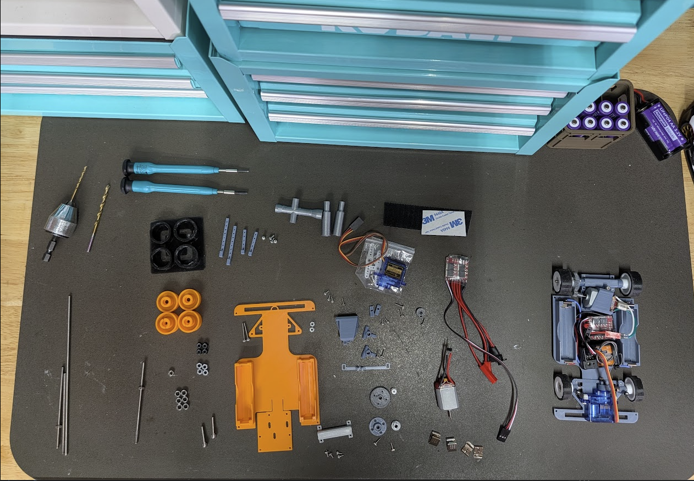
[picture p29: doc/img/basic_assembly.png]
basic_assembly (https://www.youtube.com/watch?v=5ow8rVMhNYM)

Click for timelapse video.

## Basic Assembly ##
assebly_parts

### Step 1 ###
- M2x16 (2x) front screws through the floor pan for steering knuckles
- 2mm drill bit to clean our vertical tube section of steering knuckles
- M3x16 (2x) front axle screws through steering knuckles
- Steering knuckles placed over M2x16 screws
- M2 (2x) nuts on top of M2x16 screws to hold down steering knuckles
- M2x6 or M2x8 (2x) to hold Steering Link to each side steering knuckle

### Step 2 ###
- M2x6 or M2x8 (2x) to attach Steering servo to servo mount
- Decide whether you're going to use the provided steering servo arm and trim to size (recommended), or use the printed servo arms
- M2x6 (1x) into steering servo arm to line up with Steering Link, trim arm with side-cutters if necessary
- It is a good idea to power up the servo to get it to a neutral position before mounting the steering servo arm
- Servo-provided screw to mount servo arm
- M2x4 (2x) up through main plate to attach Servo Mount to chassis

### Step 3 ###
If you are using the AA battery sizes, cut 3 sections of about 8cm of wire.
Strip the ends of the wire about 1.5mm. Solder one wire to a negative terminal.
Solder one wire to a positive terminal. The third wire will connect the second 
positive terminal to the second negative terminal, creating a series battery configuration.

On the remaining positive and negativee ends, these should get a connector, or
be soldered directly to the input of the ESC. See [Electronics](electronics.md).

### Step 4 ###
- M2x4 (4x) up through chassis to Threaded Rear Axle Mount, with the wedge shape
facing forward.
- MR63ZZ (2x) bearings pressed into each side of the Axle Mount

Now we need to super-glue an M3 nut onto one side of the 75mm Threaded M3 Rod that
we are going to use as our axle. Set the axle through the Rear Axle Mount, and try
to center it by eye with the chassis. Take a metal M3 nut, and thread it onto the 
right side (gear side) of the axle until it is just touching the bearing. You will 
have to keep re-centering and adjusting, as the axle is certainly going to move 
while doing this.

Once you are satisfied with the centering and where the axle sits relative to the chassis,
remove the axle.

Set the axle on something in such a way that the M3 nut is not touching anything, and then
apply a small dab of super glue to each side of the nut. Allow it to dry for 5 minutes.

This nut becomes our solid drive point through the axle. It is certainly possible to break
the nut loose with time or with high powered motors, so you may have to repair this 
in the future.

### Step 5 ###
- Place the glued rear axle into the Rear Axle Mount with the M3 nut to the right
of the chassis (gear side)
- Thread another M3 nut (1x) on the left side of the axle, but not all the way to the bearing
- Optional, ream the Axle Spacer with a 3mm drill bit
- Place the Rear Axle Spacer on the left side and line up the hex cutout with the M3 nut,
once in place the nut should be almost completely covered by the space
- Gently tighten the Spacer+Nut until they are almost touching the left side bearing, there should
be about 0.25mm of play in order to allow the Axle to spin freely on the bearings. We can adjust
this later.
- M2x6 (at least 2x) screws are used to hold the 42 Main Gear to the Threaded Solid Axle Gear Mount. The
screws should go through the back side (inward of car) of the mount and thread into the gear.
- Optional, ream the Threaded Solid Axle Gear Mount with a 3mm drill bit
- Press the Gear assembly onto the axle, and align the hex cutout with the glued M3 nut. The gear now
becomes our solid point for holding the axle during wheel installation and adjustment.

### Step 6 ###
- Install the Right Rear Wheel. Press onto the axle until the two alignment pins line up with the Gear assembly.
- Use an M3 nut to secure the Right Rear Wheel to the Gear assembly, holding the Gear with one hand
- Install the Left Rear Wheel. Press onto the axle until the two alignments line up with the Axle Spacer.
- Hold the Gear assembly with one hand, and install an M3 nut onto the Left Rear Wheel to secure it
- You will almost certainly have to adjust the tension on the rear axle to get it to spin freely without much
back and forth play. To do this, you can hold the Gear assembly with one hand, and physically turn/rotate the 
Left Rear Wheel, which will in turn move the Left Side Spacer and M3 nut. If you Loosen the wheel 
(rotate counter clockwise), it will press more tightly against the M3 nut on the outside of the wheel, 
creating a more secure wheel installation.

It is crucial that you get a feel for the rear axle, so you can spot when issues arise during
use of the car. For instance, you may see the axle tighten itself and become unable to spin, and
the car will slow down or be unable to drive.

### Step 7 ###
- Install two MR63ZZ bearings (4x) in each front wheel, pressing them in with a small screwdriver or pen
- Install each front wheerl with an M3 nut. You may have to use a hex key on the M3 Axle to keep the axle
from backing out
- Tighten the M3 nut until the wheel spins freely but has minimal side to side play. If the wheel does
not turn smoothly, or wobbles, your bearings might not be aligned inside the wheel, and you may have to
re-install or use a hobby knife to clean up the bearing surfaces in the wheels

### Step 8 ###
- Install your 10T pinion onto your 130 motor. If you are using a printed pinion, you should
be able to firmly press the pinion onto the motor against a hard surface
- Place three M3 nuts (non-locking) inside the motor mount hexagon recesses. You will have to 
be cautious about how you hold the mount during the rest of the process
- Install your 130 motor into the Tilted Rear motor mount, where the clamp screw will face the 
back of the chassis, and the pinion gear will be on the right side of the car
- Use three M2x4 screws up through the rear of the chassis to secure the motor mount to the chassis. 
You may have to set the chassis up or hanging off the edge of a table so you can work underneath
the car to get the screws installed. Do not tighten these screws yet, just get them started.
- Align the motor mount so the Pinion Gear meshes completely with the Main Gear. You may need
to slide the motor mount backward or forward, and slide the motor left or right inside the mount.
- Secure the 3 underside screws to fix the motor mount in position, once aligned
- Use an M2x6 screw and M3 nut to secure the clamp side of the 130 motor mount, once motor is aligned

### Step 9 ###
Next you will need to install the electronics. There are many variations here, so it will
be impossible to completely generalize the instructions.

- Your Servo control wire needs to connect to your Receiver in channel 1
- Your ESC control wire needs to connect to your Receiver in channel 2
- Your ESC power input will need to connect to your battery source connector
- Your ESC output wires (2 wires) will need to connect to the 130 motor

You can fashion a connector setup between the Motor and ESC, or you can just solder the
ESC output directly to the motor. However, if the motor spins backward, you may have to 
resolder the wires, swapping them, so the motor turns in the right direction when the
throttle is applied.

Secure your electroncis to the car chassis using hook-and-loop tape, or some other secure method.

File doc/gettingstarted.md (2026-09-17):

# Getting Started #

This guide will walk you through printing and assembling the most basic car.

## Hardware ##
See the [Materials](materials.md) documentation for specific pieces. You will
need:
- M2 Screws and nuts (See [Materials](materials.md))
- Some M3 Screws and nuts (See [Materials](materials.md))
- M3 Threaded rod, cut down between 70-75mm (See [Materials](materials.md), [Assembly](assembly.md))
- A 130-size DC motor (See [Electronics](electronics.md))
- A Brushed motor Electronic Speed Controller (ESC) (See [Electronics](electronics.md))
- A battery configuration (See [Batteries](batteries.md))
  - 2x LiFePO4 14500 size (AA) with charger
    - Battery terminal connectors
  - OR a 2S LiPo / LiIon battery
    - Appropriate connectors (XT-30 or JST)
  - An appropriate charge for either setup
- A Transmitter and Receiver (See [Transmitters and Receivers](receivers.md))
- 2x narrow front tires
- 2x wide rear tires
- 6x MR63ZZ bearings

## Print ##
Download the latest release.
Print these parts, see [Printing](printing.md) for additional information for 
specific parts.

- 1 piece chassis `PanChassisSinglePieceMain.stl`
  - or With AA mounts if using 14500 or AA size batteries `PanChassisSinglePieceAAMain.stl`
- Steering knuckles (see [Printing](printing.md))
  - `SteeringKnuckle_Right.stl` and `SteeringKnuckle_Left.stl`
- Steering linkage `SteeringLink.stl`
- Servo Mount
  - Start with `MicroServoMountLongThrow.stl`
  - Optionally, print `MicroServoHorn5mmX9mm.stl`, but it is recommended to trim down the horns that came with your servos
- Motor mount `130MotorTiltedRearMount.stl` (see [Printing](printing.md))
- 10-tooth Pinion Gear `Pinion_10T_M05.stl`
- 42-tooth Straight Main Gear `MainGear42T_M05.stl`
- Rear Axle Mount `ThreadedRearAxleMountComnbined.stl`
- Rear Axle Spacer for left side `ThreadedRearAxleSpacer.stl`
- Rear Axle Gear Mount for right side `ThreadedSolidAxleGearMount.stl`
- 2x Front Wheel `FrontWheel.stl`
- 2x Rear Wheel with no bearing `RearWheel.stl`
- 2x M2 nut `M2PlasticWheelNut4.5mm.stl` (probably print more)
- 4x M3 nut `M3PlasticWheelNut5.5mm.stl` (probably print more)

Optionally, print some basic tools
- Pinion Puller tool `PinionPuller.stl`
- Wheel Nut Driver 4.5mm `WheelNutDriver4.5mm.stl`
- Wheel Nut Driver 5.5mm `WheelNutDriver5.5mm.stl`

## Assembly ##
See [Assembly](assembly.md).

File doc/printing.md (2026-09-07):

# Printing Tips and Tricks #
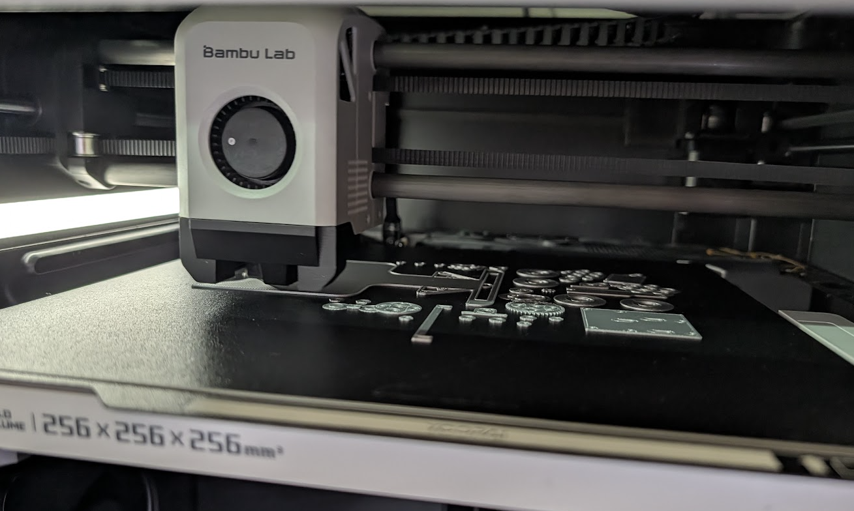
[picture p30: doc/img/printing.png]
printing


## Printer Setup ##
You do not need a large or expensive printer to print these cars. All of our test cars were printed
with a Bambu P1S, which is a mid-tier printer.

It is recommended to start by printing with PLA, as it is the cheapest and easiest to iterate with.
A PLA car is generally a great starter car, but may start to sag or warp after several hours of use.

All parts can be printed with a 0.4mm nozzle. 
It may be possible to go down to 0.2mm for smaller parts such as gears and the steering uprights to 
get better detail and require less post-processing.

It is recommended to print on a flat or semi-textured bed plate. Higher texture will generally work
but you may run into surface-to-surface issues.

PETG will work, and typically be more durable for parts like the engine mounts that take more heat,
but it is typically softer than PLA, so you may need to adjust settings or add features to stiffen
your parts as you experiment.

PETG-CF has been show to print successful cars, but is not necessarily recommended, as it typically
requires additional considerations and support during printing, and often requires more post-processing.

## Basic Car Parts ##

- 1 piece chassis `PanChassisSinglePieceMain.stl`
 - or With AA mounts if using 14500 or AA size batteries `PanChassisSinglePieceAAMain.stl`
- Steering knuckles (see below)
 - `SteeringKnuckle_Right.stl` and `SteeringKnuckle_Left.stl`
- Steering linkage `SteeringLink.stl`
- Servo Mount
 - Start with `MicroServoMountLongThrow.stl`
 - Optionally, print `MicroServoHorn5mmX9mm.stl`, but it is recommended to trim down the horns that came with your servos
- Motor mount `130MotorTiltedRearMount.stl` (see below)
- 10-tooth Pinion Gear `Pinion_10T_M05.stl`
- 42-tooth Straight Main Gear `MainGear42T_M05.stl`
- Rear Axle Mount `ThreadedRearAxleMountComnbined.stl`
- Rear Axle Spacer for left side `ThreadedRearAxleSpacer.stl`
- Rear Axle Gear Mount for right side `ThreadedSolidAxleGearMount.stl`
- 2x Front Wheel `FrontWheel.stl`
- 2x Rear Wheel with no bearing `RearWheel.stl`
- 2x M2 nut `M2PlasticWheelNut4.5mm.stl` (probably print more)
- 4x M3 nut `M3PlasticWheelNut5.5mm.stl` (probably print more)

## Part-Specific Tips ##

### Steering Knuckles / Uprights ###
Print these vertically. You want the least amount of distortion on the vertical tube, since it will have 
to slide on the bolt during operation. Print with ample supports for the steering arm attachment point.

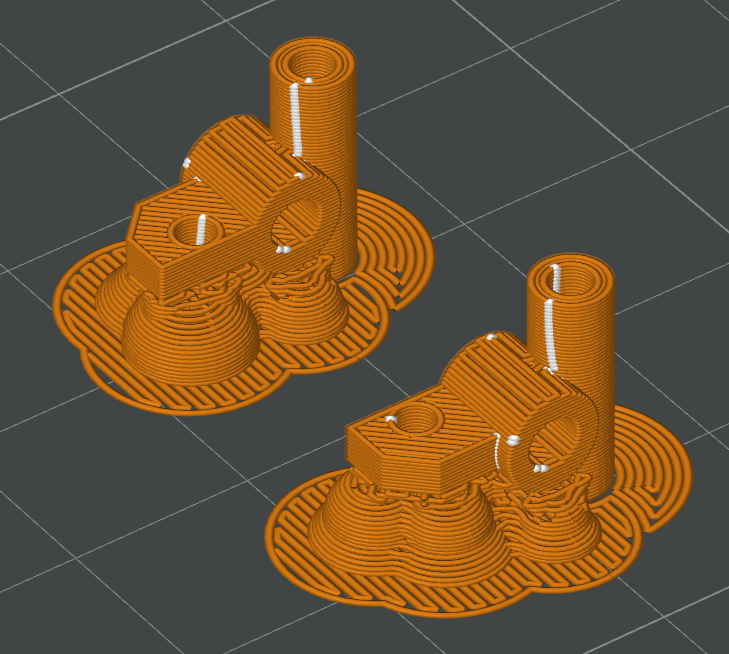
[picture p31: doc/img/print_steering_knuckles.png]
print_knuckles


### 130 Motor Flat 15 Degree ###
This is a motor mount that holds the motor at a 15 degree angle to the rear axle and drive gear, but 
allows the motor to sit flat against the rear plate. 

Print this on its side with the main structure parallel but raised up from the bed.

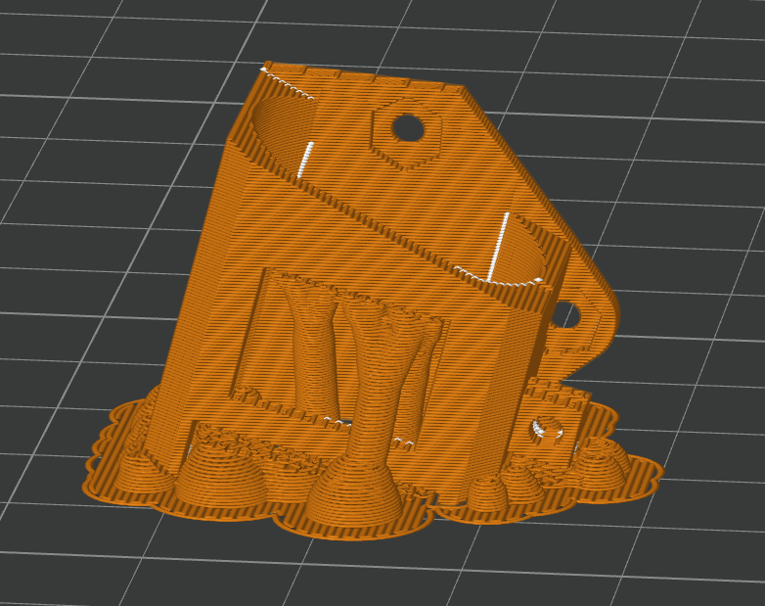
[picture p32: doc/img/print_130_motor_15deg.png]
print_130_15


### 130 Motor Tilted ###
This is a motor mount that lifs the at a 45 degree angle to clear the rear axle, much in the way of the
MR-02 2WD Kyosho cars solve this same packaging problem. 

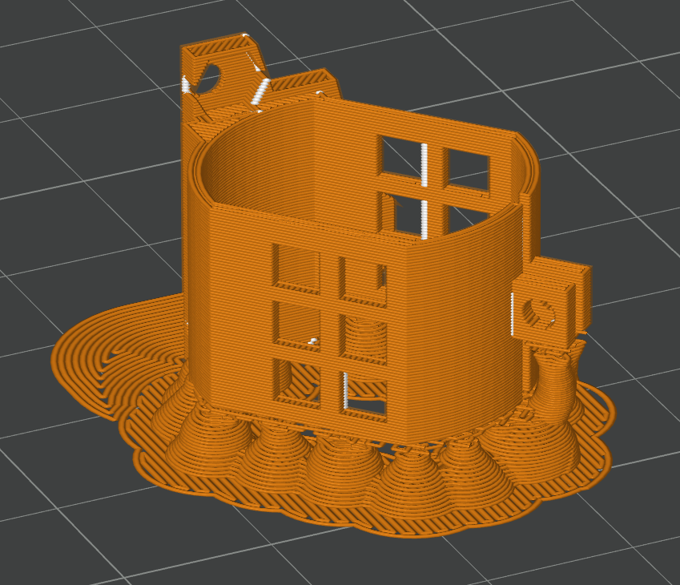
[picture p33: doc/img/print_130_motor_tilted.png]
print_130_tilt


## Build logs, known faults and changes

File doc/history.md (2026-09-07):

# Project History / Beginnings #
From Coach Kurt

## H2GP Roots ##
I coach a team in the [H2GP](https://www.h2grandprix.com/), where each car costs
thousands of dollars on top of the hundreds of hours of research and labor. 
This program, the cars, the staff, and competition are amazing. It is, however,
a high barrier of entry, and many schools can only afford to run a small handful of
teams. 

The idea to make a very simple, highly modifiable, and cost conscious car came 
from discussions in the stands and pits with other coaches and teachers during 
these events.

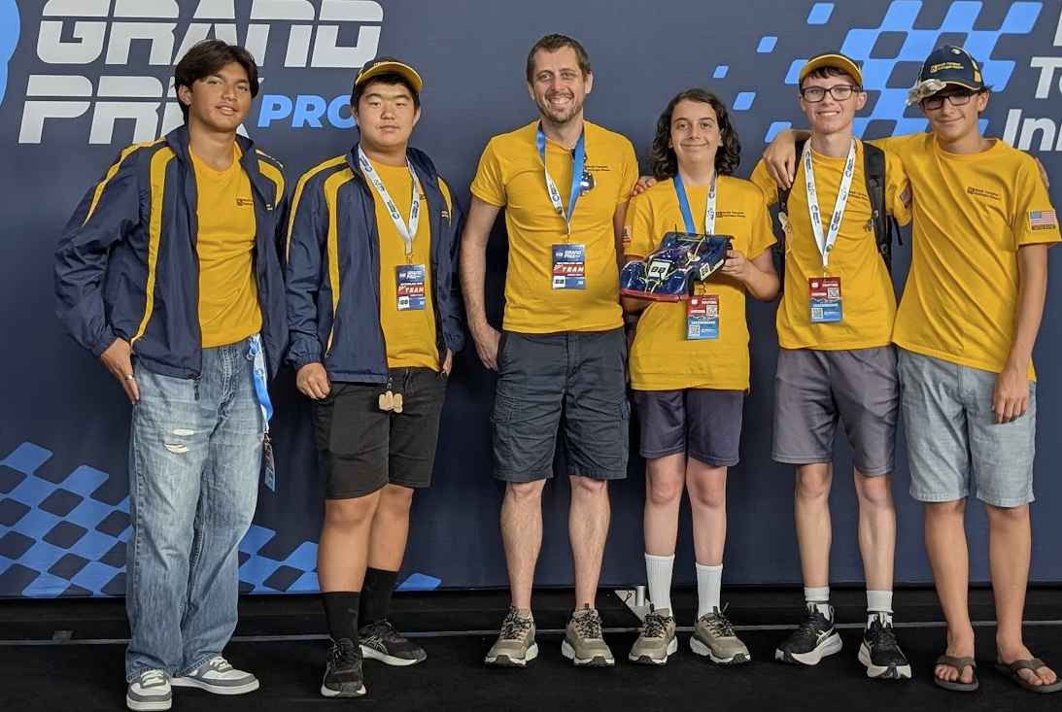
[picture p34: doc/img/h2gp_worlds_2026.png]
worlds_2026


## Philosophy ##
My original goal was to get the amortized cost of a car down to about $50. Depending
on your pre-existing knowledge, tools, etc, this project is pretty close to that, but
probably closer to $70 per car until you crest 15+ cars built. 

After letting our H2GP team bash these cars around for many hours of practice, they wanted
to push toward a new goal of making cars that are actually competitive at the 1:28 
scale against commercial alternatives. As such, many of the more recent modifications and 
additions are moving in that direction. Right now, we have cars that are close in 
overall performance to box-stock 1:28 cars that can be built for under $100. 

Once I saw what high schoolers can do with the cars and these files, I'm altering my
goals a bit more. I want this project to provide a competitive and cost-conscious foundation
that allows experimenters to achieve truly competitive cars.

## Development ##
This project is currently entirely done in FreeCAD. This was partly a challenge to 
myself to learn a new tool, but also a decision to move toward something both free 
and more accessible than tools like OpenSCAD that I had previously used to teach CAD.

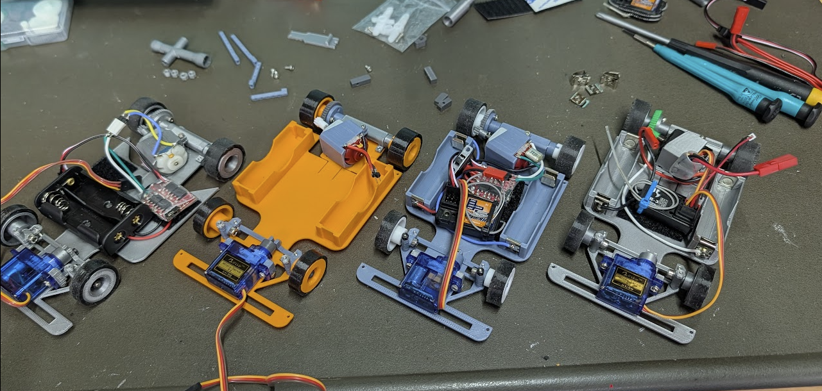
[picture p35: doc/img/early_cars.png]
early_cars


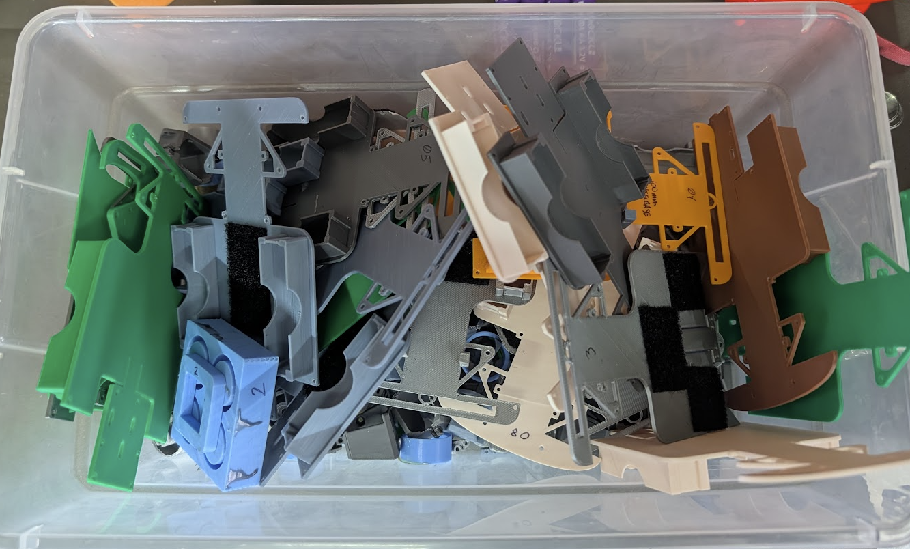
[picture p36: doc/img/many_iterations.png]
iterations


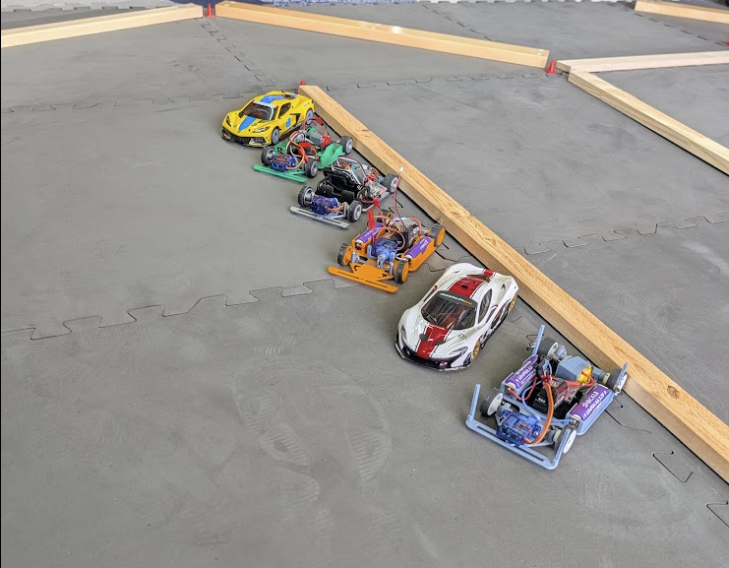
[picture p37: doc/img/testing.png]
testing1


testing2

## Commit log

2026-08-21 First commit with the Gen 4-ish version of the car
    [Mini_128_Car.FCStd]
2026-08-22 Attempt to split into smaller CAD files via script
    [00_CarAssembly.FCStd, 00_GeometryReference.FCStd, 00_RearPanPlateFlatMount.FCStd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]
2026-08-23 cleaning up CAD files and inspecting
    [01_PanChassisTwoPiece.FCStd, 02_WheelProxies.FCStd, 03_Servo.FCStd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]
2026-08-24 more cleanup work on the new files
    [01_PanChassisTwoPiece.FCStd, 04_Gears.FCStd, 15_1410MotorFlatRear.FCStd]
2026-09-03 removing original cad file
    [15_1410MotorFlatRear.FCStd, Mini_128_Car.FCStd]
2026-09-07 adding some doc and images
    [14_130MotorFlatRear.FCStd]
2026-09-07 adding export documentation
    [15_1410MotorFlatRear.FCStd]
2026-09-17 Updating doc with corrected bearings info
2026-10-04 added videos for tires and assembly
